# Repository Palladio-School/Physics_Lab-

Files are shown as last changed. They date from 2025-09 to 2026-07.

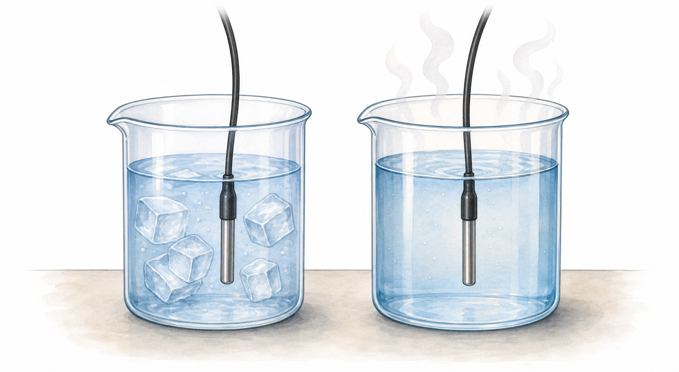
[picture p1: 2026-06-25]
docs/assets/heat-ds18b20-illustration.png

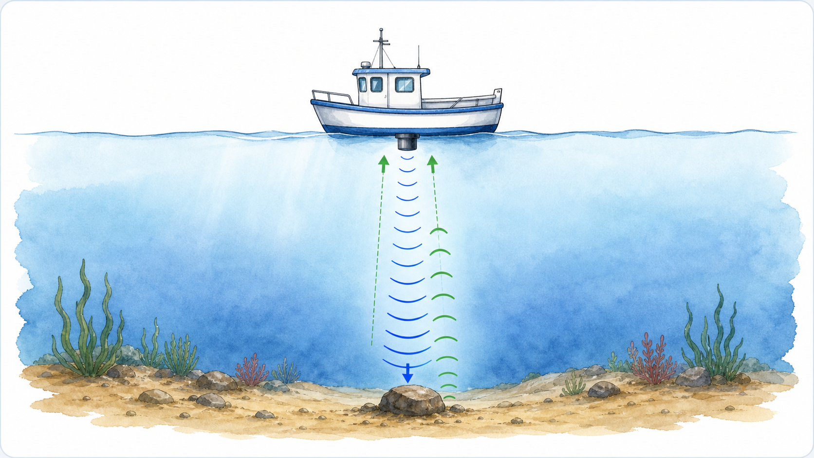
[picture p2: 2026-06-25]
docs/assets/sonar-distance-illustration.png

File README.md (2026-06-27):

# Palladio Physics Lab

Palladio Physics Lab is a classroom physics toolkit for live, low-cost experiments with an M5StickC Plus2 and common sensors. The current classroom path is browser-based: the M5Stick creates its own Wi-Fi access point, exposes a small HTTP API, and serves a dashboard that students or teachers open from a laptop, tablet, or phone.

The repository also keeps the earlier Python desktop application for reference and compatibility, but new classroom work should start from the M5 firmware and web dashboard.

## What It Supports

- Live acceleration and gyroscope measurements from the M5StickC Plus2.
- Load-cell force measurements through an HX711 module.
- Ultrasonic distance, velocity, and acceleration measurements through a DFRobot URM10 ultrasonic sensor.
- Temperature / thermal-equilibrium measurements through DS18B20 sensors.
- A browser dashboard with experiment selection, live graphs, CSV export, worksheet/report flows, calibration controls, and sampling-rate controls.
- A legacy Python desktop app that can still listen to UDP broadcasts from the M5.

## Repository Map

| Path | Purpose |
| --- | --- |
| `Physics_Lab/Physics_Lab.ino` | Main Arduino firmware for the M5StickC Plus2. It creates the Wi-Fi AP, reads sensors, serves API endpoints, and emits UDP packets for the legacy desktop app. |
| `Physics_Lab/web_dashboard.h` | Lightweight firmware-served API status page embedded into the sketch. |
| `Physics_Lab/logo_asset.h` | Generated C header containing the Palladio logo bytes for firmware use. |
| `Physics_Lab/assets/` | Firmware-side project assets, currently the Palladio logo. |
| `Physics_Lab/scripts/arduino.sh` | Helper for compiling, cleaning, checking Arduino CLI version, and uploading firmware. |
| `Physics_Lab/PROJECT_HISTORY.md` | Development notes and operational history for the current M5/web-dashboard direction. |
| `docs/index.html` | Full GitHub Pages / browser dashboard. This is the current large UI surface and should be changed carefully. |
| `docs/assets/` | Dashboard images and experiment illustrations. |
| `physics_lab_with_angular_velocity.py` | Legacy CustomTkinter desktop app. |
| `requirements.txt` | Python dependencies for the legacy desktop app. |
| `case2.stl`, `cover.stl` | 3D-printable case/cover assets. |
| `PROJECT_STRUCTURE.md` | More detailed technical structure and known hot spots. |
| `HARDWARE_API.md` | Hardware wiring notes, firmware API reference, UDP compatibility, and verification checklist. |
| `UI_FLOW.md` | Student and teacher dashboard flow, classroom checklist, and current UI state model. |

## Run The Web Dashboard

The full dashboard lives in `docs/index.html`. To inspect it locally:

```bash
python3 -m http.server 8000 -d docs
```

Then open:

```text
http://localhost:8000
```

If GitHub Pages is enabled for the repository, it should serve the same `docs/` dashboard.

## Dashboard Safety Checks

The dashboard has lightweight regression checks for extracted helper files and the browser-only GitHub Pages surface:

```bash
npm install
npm test
```

If Playwright has not downloaded Chromium on the machine yet:

```bash
npx playwright install chromium
```

The browser smoke test serves `docs/` locally with mocked M5-shaped API responses, verifies the `docs/js/*.js` load order, checks for console/page errors, and switches through Hooke, Sonar, Pendulum, and Collision views.

For hardware-backed measurements, upload the firmware to the M5StickC Plus2 and use the device access point:

1. Upload `Physics_Lab/Physics_Lab.ino` to the M5StickC Plus2.
2. Power on or reset the M5StickC Plus2.
3. Connect the laptop, tablet, or phone to this Wi-Fi network:

```text
PhysicsLab-M5
```

4. Open this address in a browser:

```text
http://192.168.4.1
```

The M5 serves the live API from `192.168.4.1`. The full dashboard can use that API when the browser is connected to the M5 network.

## Upload Firmware

The helper script expects Arduino CLI either in `PATH`, in the standard macOS Arduino IDE bundle location, or through `ARDUINO_CLI`.

```bash
cd Physics_Lab
./scripts/arduino.sh compile
./scripts/arduino.sh upload /dev/cu.usbserial-0001
```

If the upload port changes, list boards with:

```bash
'/Applications/Arduino IDE.app/Contents/Resources/app/lib/backend/resources/arduino-cli' board list
```

The default board identifier is:

```text
m5stack:esp32:m5stack_stickc_plus2
```

Override it only when testing a different compatible board:

```bash
ARDUINO_FQBN=<fqbn> ./scripts/arduino.sh compile
```

## API Surface

The firmware exposes these browser-facing endpoints:

- `/` - lightweight device/API status page from the firmware.
- `/logo.png` - embedded Palladio logo.
- `/data` - latest device state and current readings.
- `/samples?since=<sampleId>` - batched sample retrieval without duplicating already-recorded samples.
- `/set-mode?mode=<n>` - switch active sensor/experiment mode.
- `/settings?rate=<hz>` - set supported sampling rate.
- `/calibrate?target=<name>` - run sensor zero/tare calibration for the active target.

The firmware also keeps UDP output for the legacy desktop app:

- `4210` acceleration / force from accelerometer
- `4211` angular velocity
- `4213` load-cell force
- `4215` ultrasonic motion
- `4216` temperature

## Hardware

Core hardware:

- M5StickC Plus2
- USB-C cable
- Laptop, tablet, or phone with Wi-Fi

Optional experiment hardware:

- HX711 module and load cell for force / Hooke-law style experiments
- DFRobot URM10 ultrasonic sensor for distance and motion
- DS18B20 temperature sensors for thermal-equilibrium experiments
- Breadboard and jumper wires

Current firmware pin notes:

- DFRobot URM10: `TRIG_PIN = 26`, `ECHO_PIN = 25`
- HX711: `DT = 36`, `DT_ALT = 25`, `SCK = 26`
- DS18B20: `TEMP1_PIN = 25`, `TEMP2_PIN = 26`

On startup the firmware attempts to detect the connected external sensor family and selects the matching mode automatically: DS18B20 heat first, then URM10 ultrasonic, then HX711 force. Manual mode selection from the dashboard or M5 buttons remains available.

Some pins are shared across experiment modes. Treat this as a documented hardware constraint until the wiring plan is finalized per lab setup.
With the current wiring, the DFRobot URM10 and the two DS18B20 sensors both use `G25/G26`, so do not keep them connected at the same time.

## Run The Legacy Desktop App

The Python app is still useful for reference, older demos, and UDP compatibility checks.

```bash
python3 -m venv .venv
source .venv/bin/activate
pip install -r requirements.txt
python physics_lab_with_angular_velocity.py
```

## Known Hot Spots

- `docs/index.html` is currently a large single-file dashboard. Prefer documentation and small isolated changes before deep UI refactoring.
- The dashboard polls the M5 API frequently. Firmware sample IDs reduce duplicate samples, but performance should still be watched on lower-power devices.
- Sensor wiring and shared pins need a stable classroom-facing hardware guide before broad use.
- Arduino compile/upload validation depends on a local Arduino CLI + M5Stack board setup.
- The legacy Python app and current browser dashboard now describe different generations of the project; keep future changes explicit about which path they affect.

See `PROJECT_STRUCTURE.md` for the fuller technical map.
See `HARDWARE_API.md` for the hardware and API reference.
See `UI_FLOW.md` for the student and teacher classroom flow.

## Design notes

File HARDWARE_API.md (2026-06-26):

# Hardware And API Reference

This document describes the current M5StickC Plus2 hardware contract and firmware API used by the Palladio Physics Lab dashboard. It is documentation-only: it records the current implementation so future hardware, UI, and performance work can be reviewed against a shared map.

## Current Hardware Role

The M5StickC Plus2 is the measurement device and local API server.

- It creates the Wi-Fi network `PhysicsLab-M5`.
- It serves HTTP on `http://192.168.4.1`.
- It samples the active sensor mode at the configured rate.
- It exposes the latest reading and a rolling sample buffer through HTTP.
- It still broadcasts UDP packets for the legacy Python desktop app.

The full classroom dashboard in `docs/index.html` defaults to `http://192.168.4.1`, but can be pointed to another device URL with:

```text
?device=http://192.168.4.1
```

The selected device URL is stored in browser `localStorage` under `palladio-device-url`.

## Sensor Modes

| Mode | Firmware name | Dashboard use | Hardware |
| --- | --- | --- | --- |
| `0` | `Acceleration` | Acceleration, force-from-acceleration activities | Built-in M5StickC Plus2 IMU |
| `1` | `Gyroscope` | Rotation / angular velocity | Built-in M5StickC Plus2 IMU |
| `2` | `Load Cell` | Force, Hooke's law, buoyancy force readings | HX711 + load cell |
| `3` | `WiFi Info` | Device network status on the M5 display | M5StickC Plus2 only |
| `4` | `Ultrasonic` | Distance, speed, acceleration, sonar-style activities | DFRobot URM10 ultrasonic sensor |
| `5` | `Temperature` | Heat / thermal-equilibrium activities | Two DS18B20 temperature sensors |

The M5 buttons also cycle modes:

- Button A: next mode
- Button B: previous mode

Changing mode clears the sample buffer and resets mode-specific state.

## Pin Map

Current firmware definitions:

```cpp
#define TRIG_PIN 26
#define ECHO_PIN 25
#define DT 36
#define DT_ALT 25
#define SCK 26
#define TEMP1_PIN 25
#define TEMP2_PIN 26
```

| Sensor | Signal | M5 pin | Notes |
| --- | --- | --- | --- |
| DFRobot URM10 | Trigger | `G26` | Shared with HX711 SCK and DS18B20 T2 in the current firmware. |
| DFRobot URM10 | Echo | `G25` | Input. Powered from 3V in the current classroom wiring. Shared with HX711 alternate DOUT and DS18B20 T1. |
| HX711 | DOUT primary | `G36` | Firmware starts here. |
| HX711 | DOUT alternate | `G25` | Firmware can switch here if the primary path looks unavailable. |
| HX711 | SCK | `G26` | Shared with ultrasonic trigger and DS18B20 T2. |
| DS18B20 T1 | Data | `G25` | Shared with HX711 alternate DOUT. |
| DS18B20 T2 | Data | `G26` | Shared with HX711 SCK and ultrasonic trigger. |

Because some pins are shared, treat the current setup as one active external sensor family at a time unless a final wiring harness proves otherwise.
In particular, the DFRobot URM10 and the two DS18B20 temperature sensors both occupy `G25/G26`; disconnect one sensor family before testing the other.

On startup the firmware runs a conservative sensor auto-detection pass. It checks for two DS18B20 sensors first, then URM10, then HX711. The URM10 check runs before the HX711 alternate `DT_ALT = G25` check so the shared echo/DOUT pin is not misclassified as a load-cell signal. If exactly one sensor family is found, the M5 selects that mode automatically. If nothing is found or the wiring is ambiguous, it falls back to manual mode selection.

## Hardware Notes By Experiment

### Built-In IMU

Modes:

- `0` acceleration
- `1` gyroscope

No external wiring is required. The firmware converts acceleration readings to m/s² by multiplying raw accelerometer values by `9.81`.

### HX711 Load Cell

Mode:

- `2` load cell / force

Current firmware behavior:

- Uses `SCALE_FACTOR = 48163.7`.
- Starts with `DT = 36`, `SCK = 26`.
- If the HX711 is not ready or keeps returning raw zero, the firmware can try `DT_ALT = 25`.
- `calibrate?target=force` runs `scale.tare(10)`.
- Force is reported in newtons as `force`.

Open verification items:

- Confirm the load-cell capacity and mechanical mounting.
- Confirm final DOUT pin for the classroom harness.
- Calibrate `SCALE_FACTOR` against known masses before treating force values as final.

### Ultrasonic Sensor

Mode:

- `4` ultrasonic

Current firmware behavior:

- Trigger pin: `G26`.
- Echo pin: `G25`.
- Sends a 10 microsecond trigger pulse.
- Uses `pulseIn(ECHO_PIN, HIGH, 30000)`.
- Converts duration to distance with speed of sound in air: `duration * 0.0343 / 2`.
- Rejects readings below 2 cm or above 200 cm.
- Applies smoothing: previous smoothed value `60%`, new reading `40%`.
- Computes distance in meters, velocity in m/s, and acceleration in m/s² from sample timing.
- `calibrate?target=distance` zeroes the current distance as an offset and resets velocity/acceleration state.

Open verification items:

- Confirm the URM10 is powered from the M5 `3V` pin so the echo signal stays 3.3 V logic compatible.
- Test known distances in the intended classroom range.
- Confirm that smoothing is appropriate for fast-motion experiments.

### DS18B20 Temperature Sensors

Mode:

- `5` temperature

Current firmware behavior:

- Sensor 1 data pin: `G25`.
- Sensor 2 data pin: `G26`.
- Uses two OneWire buses and DallasTemperature.
- Sets both sensors to 11-bit resolution.
- Reports `temp1`, `temp2`, and `tempDelta = temp1 - temp2`.
- Skips a sample if either sensor reports disconnected.

Open verification items:

- Confirm whether the final harness uses one shared OneWire bus or two separate buses.
- Confirm pull-up resistor placement.
- Test response time in the actual thermal-equilibrium setup.

## HTTP API

Base URL when connected to the M5 access point:

```text
http://192.168.4.1
```

The firmware includes CORS headers:

- `Access-Control-Allow-Origin: *`
- `Access-Control-Allow-Methods: GET, OPTIONS`
- `Access-Control-Allow-Headers: Content-Type`
- `Access-Control-Allow-Private-Network: true`

### `GET /`

Returns the lightweight firmware-served status page from `Physics_Lab/web_dashboard.h`.

This is not the full classroom dashboard in `docs/index.html`.

### `GET /logo.png`

Returns the embedded Palladio logo from `logo_asset.h`.

### `GET /data`

Returns the latest device state and latest sample values.

Example shape:

```json
{
  "mode": 0,
  "modeName": "Acceleration",
  "ap": "PhysicsLab-M5",
  "ip": "192.168.4.1",
  "battery": 4.05,
  "sampleId": 123,
  "sampleMs": 45678,
  "sampleRate": 10,
  "ax": 0.012,
  "ay": -0.034,
  "az": 9.801,
  "gx": 0.000,
  "gy": 0.000,
  "gz": 0.000,
  "force": 0.000,
  "distance": 0.000,
  "velocity": 0.000,
  "acceleration": 0.000,
  "temp1": 0.000,
  "temp2": 0.000,
  "tempDelta": 0.000
}
```

Notes:

- Values for inactive sensor families may remain from the last sampled value or default to zero.
- `sampleMs` is firmware time from `millis()`, not browser time.
- `sampleId` increases only when the active mode produces a valid sample.

### `GET /samples`

Returns the rolling sample buffer.

```text
GET /samples
GET /samples?since=<sampleId>
```

Response shape:

```json
{
  "mode": 4,
  "modeName": "Ultrasonic",
  "ap": "PhysicsLab-M5",
  "ip": "192.168.4.1",
  "battery": 4.02,
  "sampleRate": 10,
  "latestId": 123,
  "bufferCount": 120,
  "samples": [
    {
      "mode": 4,
      "sampleId": 122,
      "sampleMs": 45600,
      "sampleRate": 10,
      "battery": 4.02,
      "ax": 0.000,
      "ay": 0.000,
      "az": 0.000,
      "gx": 0.000,
      "gy": 0.000,
      "gz": 0.000,
      "force": 0.000,
      "distance": 0.340,
      "velocity": 0.120,
      "acceleration": -0.030,
      "temp1": 0.000,
      "temp2": 0.000,
      "tempDelta": 0.000
    }
  ]
}
```

Notes:

- The firmware stores up to 512 samples in a circular buffer.
- `since` filters samples with `sampleId > since`.
- If there are no newer samples, `samples` is an empty array.
- The dashboard polls this endpoint first and falls back to `/data`.

### `GET /set-mode?mode=<n>`

Switches active mode and returns the same shape as `/data`.

Valid modes:

- `0` acceleration
- `1` gyroscope
- `2` load cell
- `3` Wi-Fi info
- `4` ultrasonic
- `5` temperature

Changing mode:

- configures mode-specific hardware,
- clears the sample buffer,
- resets distance/velocity state,
- resets sampling schedule,
- updates the M5 display.

### `GET /settings?rate=<hz>`

Updates sample rate and returns the same shape as `/data`.

Accepted rates:

- `1`
- `2`
- `5`
- `10`
- `20`
- `50`
- `100`

Notes:

- The default rate is 10 Hz.
- Entering load-cell mode forces the rate back to 10 Hz.
- The dashboard exposes the same values in its sampling-rate dropdown.

### `GET /calibrate?target=<name>`

Runs calibration/zeroing for the requested target and returns the same shape as `/data`.

Valid targets:

| Target | Effect |
| --- | --- |
| `accel` | Stores current raw acceleration as offset and reports zeroed acceleration. |
| `gyro` | Stores current raw gyroscope values as offset and reports zeroed angular velocity. |
| `force` | Runs HX711 tare with 10 samples and resets force zero state. |
| `distance` | Adds current distance to the distance offset and resets velocity/acceleration state. |

The current dashboard maps calibration buttons by active mode:

- mode `0` -> `accel`
- mode `1` -> `gyro`
- mode `2` -> `force`
- mode `4` -> `distance`

## UDP Compatibility

The firmware continues to broadcast UDP packets to:

```text
192.168.4.255
```

Current ports:

| Port | Mode | Payload |
| --- | --- | --- |
| `4210` | acceleration | `ax,ay,az,battery` |
| `4211` | gyroscope | `gx,gy,gz,battery` |
| `4213` | load cell | `force,battery` |
| `4215` | ultrasonic | `distance,velocity,acceleration` |
| `4216` | temperature | `temp1,temp2,tempDelta,battery` |

The legacy desktop app depends on these broadcasts. New browser work should prefer HTTP `/samples` and `/data`.

## Dashboard API Behavior

The full dashboard:

- builds API URLs from `deviceBaseUrl`;
- defaults to `http://192.168.4.1`;
- polls `/samples?since=<lastSampleId>`;
- falls back to `/data` if `/samples` fails;
- schedules polling adaptively from the active sample rate instead of using a fixed 30 ms hardware loop;
- polls more slowly while measurement is idle and backs off when the M5 is offline;
- temporarily uses `/data` first when `/samples` is unavailable, then retries `/samples` periodically;
- uses firmware `sampleId` and `sampleMs` to avoid duplicate samples and browser-time drift;
- sends `/set-mode`, `/settings`, and `/calibrate` through simple GET requests.

The pendulum experiment is digital-only and does not require M5 hardware.

## Verification Checklist

Before broad classroom use, verify with the actual hardware kit:

- M5 boots and advertises `PhysicsLab-M5`.
- Browser can reach `http://192.168.4.1/data`.
- `/samples?since=0` returns sample objects in each hardware mode.
- Built-in acceleration reads near `9.81 m/s²` on the gravity axis before zeroing.
- Gyroscope reads near zero when stationary after calibration.
- HX711 tare works and known masses produce stable force readings.
- Ultrasonic readings match known distances in the expected range.
- DS18B20 sensors both report plausible temperatures and `tempDelta` behaves as expected.
- Dashboard mode switching matches firmware mode switching.
- UDP compatibility still works for the legacy Python app when needed.

## Known Hardware/API Risks

- Several external sensor definitions share pins (`G25`, `G26`). Do not assume simultaneous external sensor wiring until a final harness is tested.
- URM10 echo voltage must be checked against the M5 input tolerance if the wiring changes from the current 3V setup.
- Load-cell calibration factor is currently code-defined and should be validated against known masses.
- Adaptive polling is UI-side behavior; firmware sample IDs protect data quality, but performance should still be measured on classroom devices.
- `/data` returns one flat object for all sensor families, so consumers should read only the fields relevant to the active mode.
- API changes should preserve `sampleId`, `sampleMs`, and `/samples?since=` semantics because the dashboard depends on them.

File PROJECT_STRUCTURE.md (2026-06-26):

# Project Structure

This file maps the current repository before larger documentation, hardware, UI, or performance work. The goal is to make the first cleanup step readable without changing the dashboard implementation.

## Current Product Shape

Physics Lab has two generations in the same repository:

1. Current M5/web-dashboard flow
   - `Physics_Lab/Physics_Lab.ino` runs on the M5StickC Plus2.
   - The M5 creates the `PhysicsLab-M5` Wi-Fi network and exposes the hardware API at `http://192.168.4.1`.
   - `docs/index.html` is the full classroom dashboard, suitable for GitHub Pages or local browser use.

2. Legacy desktop flow
   - `physics_lab_with_angular_velocity.py` is a Python / CustomTkinter app.
   - The firmware still broadcasts UDP packets for compatibility with this app.

New work should state which flow it changes.

## Directory And File Responsibilities

### Root

- `README.md` - main project entry point for teachers, developers, and maintainers.
- `PROJECT_STRUCTURE.md` - this technical map.
- `HARDWARE_API.md` - hardware wiring notes, firmware API reference, UDP compatibility, and verification checklist.
- `UI_FLOW.md` - student and teacher dashboard flow, classroom checklist, and current UI state model.
- `requirements.txt` - Python dependencies for the legacy desktop app only.
- `physics_lab_with_angular_velocity.py` - legacy desktop application.
- `case2.stl`, `cover.stl` - 3D-printing assets for the device/case.

### `Physics_Lab/`

- `Physics_Lab.ino` - main firmware sketch.
- `web_dashboard.h` - embedded lightweight device status page.
- `logo_asset.h` - generated byte-array logo asset.
- `assets/palladio-logo.png` - source logo asset used for firmware embedding.
- `PROJECT_HISTORY.md` - project-local history and operational notes.
- `scripts/arduino.sh` - Arduino CLI helper.

### `docs/`

- `index.html` - full browser dashboard UI.
- `.nojekyll` - keeps GitHub Pages from applying Jekyll processing.
- `assets/` - dashboard illustrations and experiment images.

## Firmware Responsibilities

The firmware:

- Creates the M5 Wi-Fi access point.
- Reads the active sensor mode.
- Maintains `sampleId`, `sampleMs`, and `sampleRate` so browser polling does not duplicate samples.
- Serves the latest reading and sample batches through HTTP.
- Handles mode changes, sampling-rate changes, and calibration requests.
- Keeps UDP compatibility with the older Python app.

Important endpoints:

- `/`
- `/logo.png`
- `/data`
- `/samples`
- `/set-mode`
- `/settings`
- `/calibrate`

## Dashboard Responsibilities

The full dashboard in `docs/index.html` handles:

- Experiment selection.
- Live graphing and readouts.
- Student-facing worksheet/report interactions.
- CSV export.
- Sampling-rate and calibration controls.
- Digital-only experiments such as the pendulum simulation.
- M5 API polling through the `192.168.4.1` device endpoint when hardware is connected.

Because it is currently a large single HTML file, changes should be narrow and easy to review.

## Hardware Matrix

| Experiment / Mode | Hardware | Firmware Notes |
| --- | --- | --- |
| Acceleration | M5StickC Plus2 IMU | Built-in sensor. |
| Gyroscope | M5StickC Plus2 IMU | Built-in sensor. |
| Force / load cell | HX711 + load cell | Uses `DT`, `DT_ALT`, and `SCK` candidates. |
| Ultrasonic motion | DFRobot URM10 ultrasonic sensor | Uses trigger/echo pins and firmware-side timing. |
| Heat / thermal equilibrium | DS18B20 sensors | Uses two OneWire data pins. |
| Pendulum simulation | No M5 required | Digital dashboard experiment. |

Current pin definitions in `Physics_Lab.ino`:

```cpp
#define TRIG_PIN 26
#define ECHO_PIN 25
#define DT 36
#define DT_ALT 25
#define SCK 26
#define TEMP1_PIN 25
#define TEMP2_PIN 26
```

Firmware startup performs conservative sensor auto-detection. It selects Heat when both DS18B20 sensors are found, Ultrasonic when the URM10 responds to trigger/echo timing, and Force when HX711 is found. Manual selection remains available from the dashboard and M5 buttons.

Pin sharing is intentional in the current firmware mode layout, but it should be documented in a classroom wiring guide before hardware kits are handed out broadly.

## Developer Workflow

Compile firmware:

```bash
cd Physics_Lab
./scripts/arduino.sh compile
```

Upload firmware:

```bash
cd Physics_Lab
./scripts/arduino.sh upload /dev/cu.usbserial-0001
```

Run the legacy app:

```bash
python3 -m venv .venv
source .venv/bin/activate
pip install -r requirements.txt
python physics_lab_with_angular_velocity.py
```

Inspect the full dashboard locally:

```bash
python3 -m http.server 8000 -d docs
```

Then open:

```text
http://localhost:8000
```

## Known Review Points

- `docs/index.html` should eventually be split into smaller assets/modules, but that should be a separate PR.
- The README and project history should stay aligned so users know whether instructions refer to the current M5/browser flow or the legacy Python flow.
- A hardware/API guide should be the next documentation layer: wiring diagrams, pin choices, calibration steps, expected sensor ranges, and safety notes.
- Polling/performance work should be measured against actual M5 hardware and classroom browser devices.
- GitHub Pages and M5-served firmware pages are different surfaces; future docs should keep that deployment model clear.

## Suggested Next PRs

1. Polling and performance cleanup.
2. Controlled `docs/index.html` modularization.

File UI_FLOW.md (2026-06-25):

# Student And Teacher UI Flow

This document maps the current browser dashboard flow in `docs/index.html` for classroom use. It is documentation-only: it records how the dashboard is intended to be used before any UI refactor or product redesign.

## Audience And Surfaces

The dashboard serves two classroom roles:

- Students use the experiment menu, live chart, student guide, worksheets, and CSV/export actions while collecting data.
- Teachers use the same dashboard plus the right-side experiment panels, calibration controls, sampling controls, trial tables, and export/review tools to prepare and guide the activity.

The dashboard can run from:

- GitHub Pages or a local `docs/` server while pointing at the M5 API.
- The M5 access point at `http://192.168.4.1` for hardware-backed measurements.
- A local browser-only mode for digital activities such as the pendulum simulation.

## Student Flow

### 1. Choose the activity

Students start from the left experiment menu. The current dashboard groups activities by school level:

| Group | Activities |
| --- | --- |
| A Gymnasium | Distance and time, SONAR, average speed, mass/weight and spring extension, heat, simple pendulum |
| B Gymnasium | Uniform motion, Hooke's law, buoyancy, rotation |
| Technical sensor modes | Acceleration, gyroscope, force, ultrasonic, heat |

Selecting an activity updates the title, description, graph setup, active sensor mode, and the student guide prompts. The selected activity is stored in browser `localStorage` as `palladio-active-experiment`.

### 2. Connect to the measurement source

For hardware-backed activities, the student device should be connected to the `PhysicsLab-M5` Wi-Fi network and use the M5 API at:

```text
http://192.168.4.1
```

The dashboard stores the chosen device URL in `localStorage` as `palladio-device-url`. When the dashboard is opened with a query parameter such as:

```text
?device=http://192.168.4.1
```

that value becomes the active measurement source.

The simple pendulum activity is digital-only and does not require the M5.

### 3. Measure

The primary student controls are in the instrument bar:

- `Έναρξη` starts or pauses live collection.
- `Νέα μέτρηση` clears the visible run and starts a fresh trial.
- `Αποθήκευση CSV` exports the current data.
- The calibration button runs the relevant zero/tare action when the active sensor supports it.

During live collection, the student guide treats the first state as measurement. The chart updates from `/samples?since=<sampleId>` when available, with `/data` as a fallback.

### 4. Observe

After samples exist, students inspect the graph:

- Toggle plotted series from the legend.
- Use value inspection to read a point.
- Use selection mode to mark an A-B region.
- Use pan/zoom and the `Live` control to move between a fixed view and real-time tracking.
- Use split view or experiment-specific chart modes where available.

For ultrasonic activities, the dashboard keeps one main series active at a time so distance, velocity, and acceleration are easier to compare without clutter.

### 5. Conclude

When students select an A-B region, the guide moves toward conclusion. The current dashboard supports this through:

- A-B selection statistics and graph annotations.
- Experiment-specific panels and tables for trials.
- Worksheet text areas for observations and conclusions.
- CSV export for follow-up analysis.

The main student loop is:

```text
Choose activity -> Start measurement -> Observe chart -> Select evidence -> Write conclusion -> Export or reset
```

## Teacher Flow

### 1. Prepare the setup

Before students start, the teacher should choose the activity and confirm that the dashboard selected the expected hardware mode:

| Activity type | Expected source |
| --- | --- |
| Acceleration / motion with IMU | Mode `0`, built-in M5 IMU |
| Rotation | Mode `1`, built-in M5 gyroscope |
| Force / Hooke / buoyancy | Mode `2`, HX711 + load cell |
| Distance / SONAR / speed | Mode `4`, ultrasonic sensor |
| Heat | Mode `5`, DS18B20 sensors |
| Pendulum | Browser simulation, no M5 polling |

Some activities apply defaults automatically. For example, force activities prefer a 10 Hz sampling rate, heat uses a longer time window, and pendulum stops hardware polling because it is simulated in-browser.

### 2. Calibrate and check readings

Teacher-facing calibration depends on the selected mode:

- Force / load cell: tare the load cell before hanging masses or collecting buoyancy data.
- Ultrasonic: zero the distance offset if the setup needs a reference position.
- Acceleration: use the built-in IMU readings as the baseline for acceleration activities.

Before distributing the activity, confirm:

- The live readout changes when the sensor changes.
- The graph updates at the intended rate.
- Units match the activity.
- The first few samples look plausible for the physical setup.

### 3. Guide the live activity

The right-side rail is the teacher's main review and facilitation area. It contains experiment-specific panels for:

- Hooke's law and force-extension work.
- Mass/weight and spring extension.
- Buoyancy force trials.
- Motion, collision, and ultrasonic analysis.
- Heat / thermal equilibrium.
- Pendulum timing and analysis.

The rail can be collapsed or resized so a projector view can emphasize either the graph or the teacher panels.

### 4. Review student evidence

During or after collection, the teacher can ask students to compare:

- Raw graph shape.
- A-B selection statistics.
- Repeated trials in the experiment tables.
- Worksheet observations and conclusion text.
- Exported CSV data when a deeper analysis is needed.

The dashboard stores several trial sets in browser `localStorage`, including collision, Hooke, weight, pendulum, and buoyancy trial data. This makes quick classroom iteration possible, but it is not a long-term student record system.

### 5. Export or reset

The teacher can use the generic CSV export or experiment-specific exports where present:

- Hooke trial export.
- Mass/weight extension export.
- Buoyancy export.
- Collision export.
- Pendulum export.

Use `Νέα μέτρηση` when the next group needs a clean run. For a completely clean classroom device, clear browser storage or use a fresh browser profile.

## Current UI State Model

The dashboard uses a simple student-guide state:

| State | Trigger | Student meaning |
| --- | --- | --- |
| Measure | Running or no sample data yet | Collect data from the device or simulation. |
| Observe | Samples exist, no A-B selection | Read the graph and compare visible series. |
| Conclude | A-B selection exists | Use selected evidence to write or discuss the conclusion. |

This state model should remain visible in future UI work because it matches the classroom rhythm of measurement, observation, and conclusion.

## Classroom Checklist

Before class:

- Upload current firmware to the M5StickC Plus2.
- Confirm the M5 starts the `PhysicsLab-M5` Wi-Fi network.
- Connect one browser device and open the dashboard.
- Select the intended experiment.
- Confirm sensor mode, sample rate, and units.
- Run calibration when the activity needs it.
- Collect a short test run and export CSV once.

During class:

- Keep one projected dashboard as the reference view.
- Use the student guide to keep the flow on measure, observe, conclude.
- Use A-B selection when asking for evidence.
- Reset between groups or trials.

After class:

- Export useful CSV or trial tables.
- Note any sensor noise, connection drop, calibration drift, or confusing UI step.

## Known UI Flow Risks

- `docs/index.html` is a large single file, so even small UI behavior changes need careful review.
- Several teacher and student controls share the same screen; future design work should clarify role-specific views without hiding advanced controls from teachers.
- Browser `localStorage` is useful for classroom continuity but can surprise users if an old activity or trial set reappears.
- Hardware-backed activities depend on the browser reaching the M5 API; the UI should eventually make connection state and recovery clearer.
- The pendulum flow is digital-only while most other activities are hardware-backed, so documentation and UI labels should keep that difference explicit.

## Suggested Follow-Up PRs

1. Add screenshots or short classroom walkthrough images after the visual flow is accepted.
2. Review dashboard copy for student-facing Greek consistency.
3. Measure polling and rendering performance on actual classroom tablets/laptops.
4. Split `docs/index.html` into smaller modules only after the documented flow is stable.

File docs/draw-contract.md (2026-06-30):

# Draw Contract

Date: 2026-06-30

This note documents the current responsibilities of `draw()` in `docs/index.html`.
It is a safety contract for future refactors. It does not change runtime behavior.

## Scope

`draw()` is the central renderer for the main chart canvas. It currently handles:

- clearing and repainting the main canvas,
- choosing special chart paths before the standard renderer,
- computing chart geometry,
- drawing axes, gridlines, labels, and plot frame,
- drawing selected data series,
- highlighting the active A-B selection,
- drawing area-under-curve shading for the active analysis series,
- drawing trend/fit lines,
- drawing A/B markers,
- drawing hover markers and tooltip anchors,
- delegating pendulum scrub/highlight overlays.

## Special Render Paths

`draw()` exits early for these cases:

1. Hooke split chart: `isHookeExperimentMode() && splitChartActive()`
2. Hooke force-extension chart: `isHookeExperimentMode() && hookeChartView === 'extension'`
3. Generic split chart: `splitChartActive()`

Any future extraction must preserve this order. The Hooke-specific split and
extension paths take precedence over the generic split chart.

## Inputs Read By `draw()`

The function reads global dashboard state, including:

- `canvas`, `ctx`
- active mode/experiment predicates
- `hookeChartView`
- `selection`
- `analysisCache`
- `hoverPoint`
- `timeScaleMode`
- `valueScaleMode`
- current rows through `visibleRows()`
- enabled series through `enabledSeries()`
- view bounds through `getViewBounds()`
- scaling through `yScale()`, `selectedTimeScale()`, and `selectedValueScale()`

Because these are shared globals, extracting `draw()` directly would be risky
unless the state is passed through an explicit render-state object.

## Outputs And Side Effects

`draw()` mutates:

- the canvas pixels,
- `chartGeometry`, used later by pointer, hover, pan, zoom, selection, and
  tooltip code.

It also calls:

- `drawHookeSplitChart()`
- `drawHookeDxChart()`
- `drawSplitChart()`
- `drawPendulumTimeGuides()`
- `drawDataPath()`
- `drawPendulumScrubHighlight()`
- `showTooltip()`

Future changes must treat `chartGeometry` as part of the public internal
contract of the chart interaction loop.

## Behavior To Preserve

- Empty datasets show `Αναμονή για μετρήσεις...`.
- Y-axis padding switches at narrow canvas width: left pad `64` under `520px`,
  otherwise `82`.
- Selection shading is clipped to the visible x-range.
- Area shading is drawn only for the selected analysis series when it is visible.
- Fit lines are dashed and clipped to the selected analysis interval.
- A/B markers are shown only when the active analysis series is visible.
- Hover tooltip follows the nearest visible row by time.
- Pendulum time guides and scrub highlight remain part of the main chart path.

## Safe Next Steps

Good first extractions:

1. A pure `buildChartRenderState()` helper that returns geometry, scales, rows,
   and selected series without drawing.
2. A pure `chartPointForRow()` helper that converts row values to canvas points.
3. Small draw helpers for axes/grid and selection shading after screenshot or
   pixel-level characterization exists.

Avoid first:

- extracting pointer/pinch/wheel behavior together with drawing,
- changing `chartGeometry` shape,
- changing the special-path order,
- changing scale defaults or padding while refactoring.

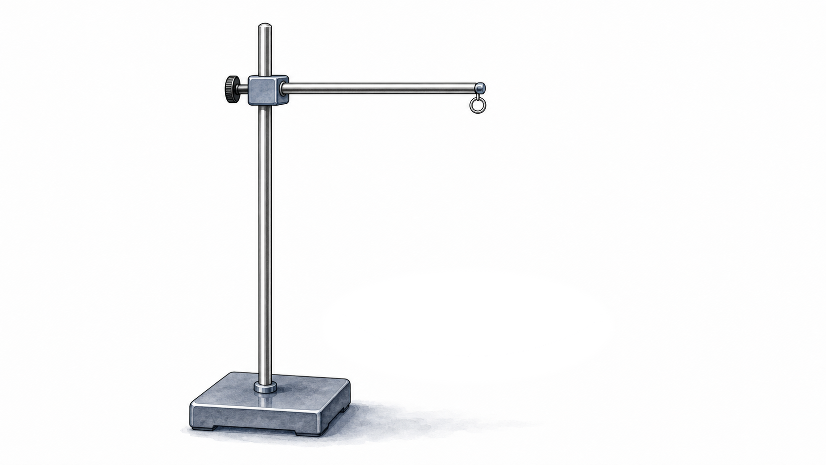
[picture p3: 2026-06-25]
docs/assets/pendulum-background-clean.png

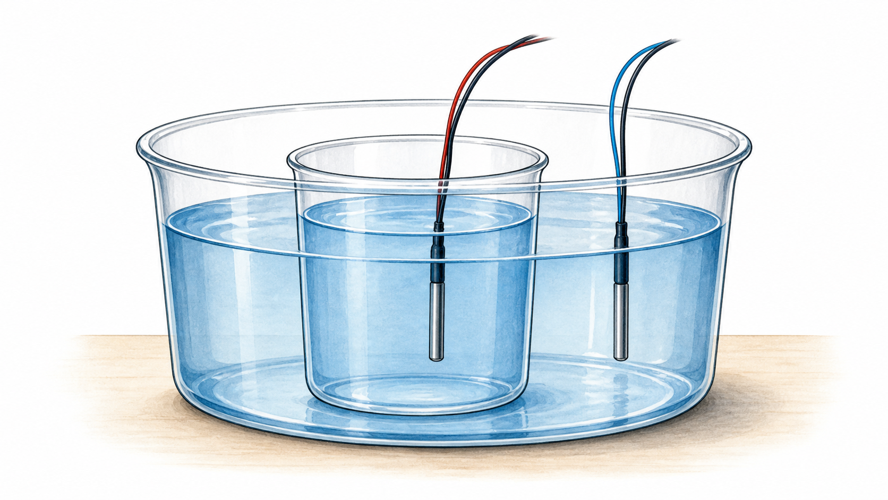
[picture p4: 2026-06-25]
docs/assets/heat-water-bath-illustration.png

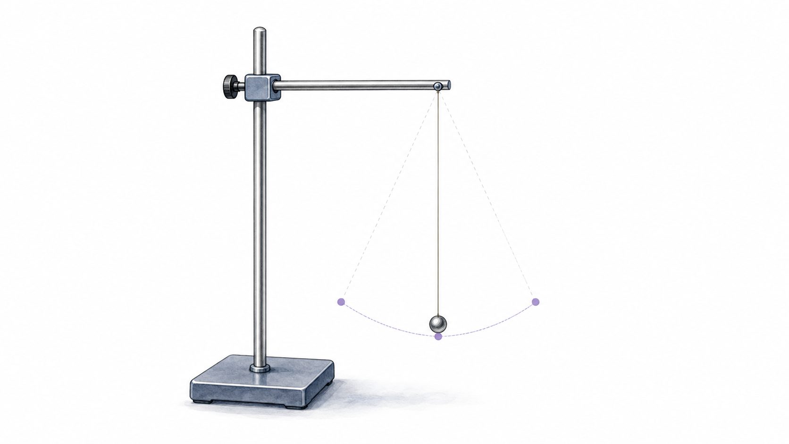
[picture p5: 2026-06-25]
docs/assets/pendulum-illustration.png

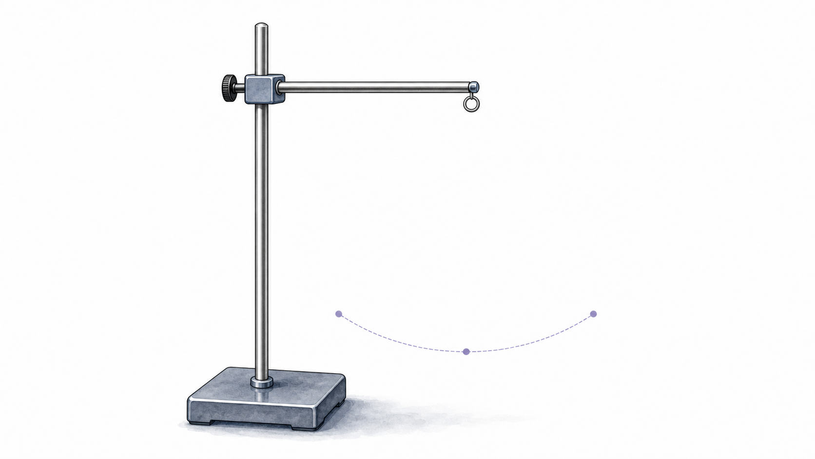
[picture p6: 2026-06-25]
docs/assets/pendulum-background-illustration.png

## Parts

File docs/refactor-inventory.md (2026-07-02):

# Refactor Inventory And Safety Net

Date: 2026-06-27

This is a documentation and test inventory only. It does not change dashboard runtime behavior, UI, firmware API, polling, or chart rendering.

## Current Size

- `docs/index.html`: 6,858 lines, 338,216 bytes.
- Extracted dashboard helpers in `docs/js/*.js`: 1,070 lines, 45,529 bytes.
- Largest remaining file by far: `docs/index.html`.

## Script Load Order

Current order in `docs/index.html`:

1. `js/experiment-catalog.js`
2. `js/app-config.js`
3. `js/device-client.js`
4. `js/storage-export.js`
5. `js/csv-row-utils.js`
6. `js/readout-utils.js`
7. `js/worksheet-utils.js`
8. `js/experiment-view-utils.js`
9. `js/sonar-utils.js`
10. `js/chart-utils.js`
11. `js/physics-calculations.js`
12. `js/fit-utils.js`
13. `js/pendulum-utils.js`
14. Inline dashboard app script

The order matters because `app-config.js` reads `window.PalladioExperimentCatalog`, `device-client.js` reads `window.PalladioConfig`, and the inline app reads all exported globals.

## Largest Remaining Blocks

Approximate ranges in `docs/index.html` after PR #15:

| Range | Lines | Area | Notes |
| --- | ---: | --- | --- |
| 927-6457 | 5,531 | Inline dashboard app | Main app state, renderers, chart drawing, events, startup. |
| 3483-5693 | 2,211 | Chart, analysis, selection, zoom | Highest-risk area. Includes `draw()` and pointer/wheel interactions. |
| 1519-3481 | 1,963 | Experiment renderers | Hooke, Sonar, Collision, Pendulum, Heat, and helper drawing code. |
| 5694-6438 | 745 | Event listeners and startup | Tightly coupled to DOM IDs and app state. |
| 977-1291 | 315 | State, element refs, row transforms | Mixed pure and UI-bound state. |
| 1-919 | 919 | HTML shell and experiment panels | Large but mostly declarative markup. |

The `draw()` function remains in place and should stay out of the next small extraction unless a stronger characterization suite is added first.
See [`draw-contract.md`](draw-contract.md) for the current chart rendering contract and safe extraction boundaries.

## Added Safety Net

- `tests/pure-helpers.test.js` loads the extracted global helper files in dependency order and checks:
  - catalog/config helpers,
  - experiment mode predicates and rail titles,
  - chart unit/format helpers,
  - weight and buoyancy calculations,
  - sonar echo-time normalization helpers,
  - pendulum period, sample, and interval helpers,
  - storage/export escaping and report generation,
  - CSV row builders for live series and saved experiment exports,
  - readout summary cards and empty table/message formatting,
  - worksheet list, Sonar worksheet row/data, and printable report helpers,
  - linear, Hooke, collision, linear-system, polynomial, and auto fit helpers.
- `tests/browser-smoke.spec.js` serves `docs/` locally with mocked M5-shaped API responses and checks:
  - script load order,
  - exported globals,
  - no `console.error` or uncaught page errors,
  - basic experiment switching for Hooke, Sonar, Pendulum, and Collision.

Run locally:

```bash
npm install
npm test
```

If Chromium is not installed for Playwright yet:

```bash
npx playwright install chromium
```

## Recommended Next Extraction Candidates

Good small PR candidates:

- More pendulum pure helpers if they stay DOM-free. The period/sample/interval helpers now live in `js/pendulum-utils.js`; keep canvas geometry and drawing in `index.html` unless separately characterized.
- More sonar helpers if they stay DOM-free. `sonarRoundTripTimeMs`, `firstFiniteNumber`, and echo-time conversion rules now live in `js/sonar-utils.js`; keep canvas drawing and drag handlers in `index.html`.
- More experiment view helpers if they stay DOM-free. Mode predicates and right-rail titles now live in `js/experiment-view-utils.js` and take an explicit state object.
- More CSV/export helpers if they stay DOM-free. Live series and saved experiment CSV rows now live in `js/csv-row-utils.js`; keep click handlers and `storageExport.downloadCsv` in `index.html`.
- More readout formatting helpers if they stay DOM-free. Summary cards and empty readouts now live in `js/readout-utils.js`; keep render decisions and DOM assignment in `index.html`.
- More worksheet/report helpers if they stay DOM-free. Motion worksheet lists and Sonar worksheet/report builders now live in `js/worksheet-utils.js`; keep user input collection and print-window opening in `index.html`.

Avoid for now:

- `draw()` and the chart interaction loop.
- `chartGeometry`, tooltip, selection, pan, zoom, and wheel/pinch handlers.
- Render functions that write directly to the DOM.
- Device polling, firmware API shape, and M5 request timing.

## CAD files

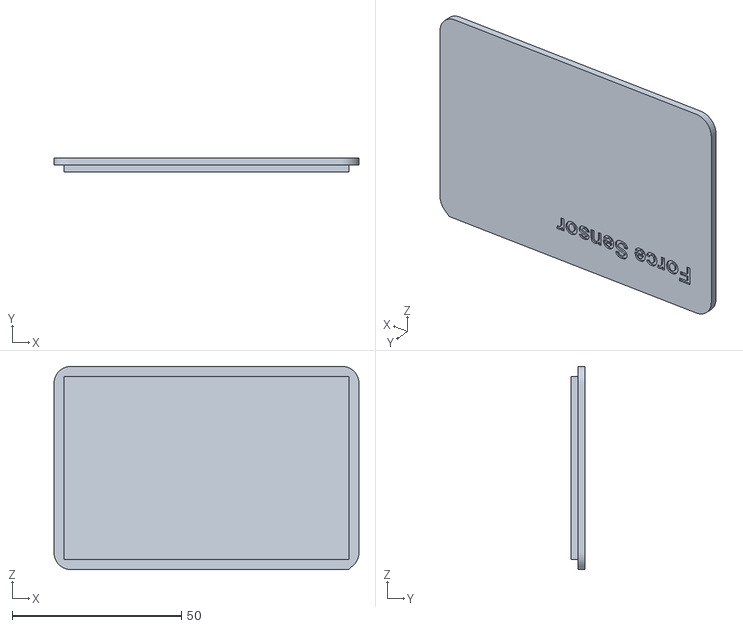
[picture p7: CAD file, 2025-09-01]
cover.stl
90.0 x 4.00 x 60.0

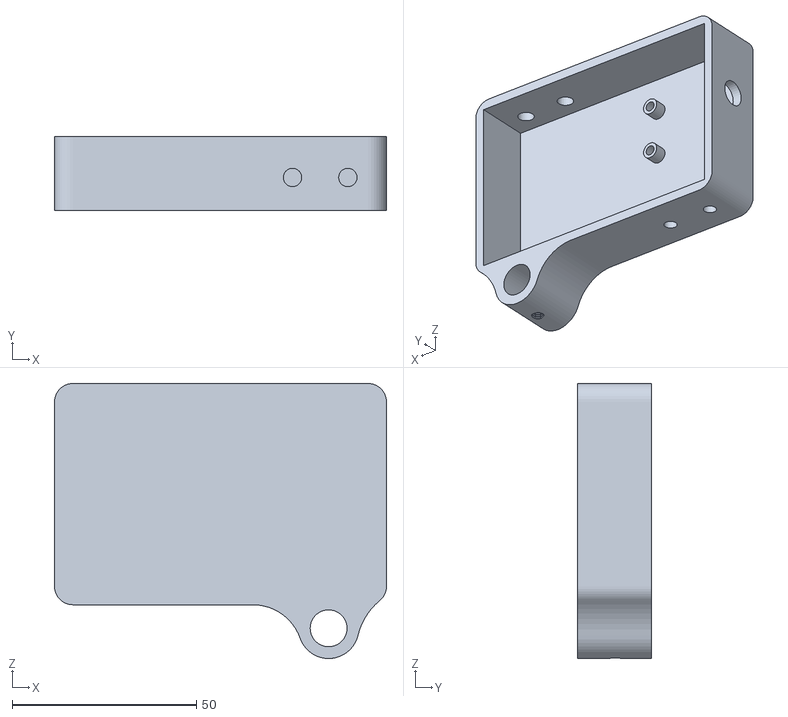
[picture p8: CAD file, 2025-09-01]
case2.stl
90.0 x 20.0 x 74.6

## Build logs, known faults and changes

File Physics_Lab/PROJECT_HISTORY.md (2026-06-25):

# Physics Lab Project History

Last updated: 2026-06-16

## Goal

Build a browser-based physics laboratory dashboard for the M5StickC Plus2. The M5Stick creates its own Wi-Fi network and serves the web app directly, so students connect to `PhysicsLab-M5` and open:

```text
http://192.168.4.1
```

## Current Status

The web app is embedded in the Arduino sketch and has been uploaded successfully to the M5StickC Plus2 several times during development.

Current main capabilities:

- Live web dashboard served from the M5StickC Plus2
- Modern sidebar UI with the Palladio logo
- Sensor modes: acceleration, gyroscope, load cell, ultrasonic motion
- Live chart with zoom, pan, series selection, and CSV export
- Analysis tools: A-B cursors, dt, dy, slope, mean, standard deviation, min/max, area, absolute area, fit equation, R2, RMSE
- Short educational examples next to each analysis/statistics tool
- Sampling-rate control: 5 Hz, 10 Hz, 20 Hz
- Firmware-side timestamps and sample IDs, so the browser does not create duplicate samples
- Calibration controls from the web UI:
  - accelerometer zero
  - gyroscope zero
  - load-cell tare
  - ultrasonic distance zero

## Files Changed Or Added

### `Physics_Lab.ino`

Main firmware sketch.

Important additions:

- Web endpoints:
  - `/`
  - `/logo.png`
  - `/data`
  - `/set-mode`
  - `/settings`
  - `/calibrate`
- Firmware-owned sampling:
  - `sampleId`
  - `sampleMs`
  - `sampleRate`
- Sampling interval control for 5/10/20 Hz
- Sensor zero/tare calibration handlers
- Serves the embedded Palladio logo as PNG

### `web_dashboard.h`

Embedded HTML/CSS/JavaScript for the web app.

Important additions:

- Full web app redesign
- Sidebar navigation and live readouts
- Palladio logo in the top-left sidebar
- Large central chart
- Chart tools:
  - inspect
  - select interval
  - pan
  - zoom in/out/live reset
- Analysis panel with statistics and physics examples
- CSV export
- Sampling-rate selector
- Calibration button that changes by sensor mode

### `logo_asset.h`

Generated C header containing the PNG logo bytes stored in flash memory.

### `assets/palladio-logo.png`

Optimized project copy of the Palladio logo used by the web app.

### `scripts/arduino.sh`

Helper script for compiling and uploading without opening Arduino IDE.

Common commands:

```bash
./scripts/arduino.sh compile
./scripts/arduino.sh upload /dev/cu.usbserial-5A490733351
```

### `.gitignore`

Ignores `.arduino/` build artifacts.

## Hardware / Board Setup

Detected board/core:

```text
M5StickCPlus2
FQBN: m5stack:esp32:m5stack_stickc_plus2
```

Arduino CLI is bundled inside Arduino IDE at:

```text
/Applications/Arduino IDE.app/Contents/Resources/app/lib/backend/resources/arduino-cli
```

Typical USB port used:

```text
/dev/cu.usbserial-5A490733351
```

If upload fails because the port disappeared, run:

```bash
'/Applications/Arduino IDE.app/Contents/Resources/app/lib/backend/resources/arduino-cli' board list
```

Then upload again with the detected USB serial port.

## Validation Already Done

The project has repeatedly passed:

- JavaScript syntax parsing via macOS JavaScript engine
- Arduino compile for M5StickCPlus2
- Upload with esptool hash verification

Recent compile size after logo and examples:

```text
Sketch uses about 37% of program storage.
Global variables use about 15% of dynamic memory.
```

## How To Use The Web App

1. Upload the sketch to the M5StickC Plus2.
2. Wait for the M5Stick to reboot.
3. Connect laptop/tablet/phone Wi-Fi to:

```text
PhysicsLab-M5
```

4. Open:

```text
http://192.168.4.1
```

5. If the old page appears, force refresh:

```text
Cmd + Shift + R
```

## Important Design Decisions

- The web app runs directly on the M5Stick. There is no external server.
- No school Wi-Fi credentials are needed.
- The dashboard polls `/data`, but records only new firmware samples using `sampleId`.
- Time values come from the M5Stick (`sampleMs`), not from browser polling time.
- Analysis examples are intentionally short and classroom-oriented.
- Ultrasonic mode shows one primary selected quantity at a time because distance, velocity, and acceleration have different units.

## Next Recommended Work

When hardware testing is available:

1. Test accelerometer zeroing on a stable table.
2. Test gyroscope zeroing while stationary.
3. Test load-cell tare with known masses and adjust calibration factor if needed.
4. Test ultrasonic distance at known distances.
5. Compare 5/10/20 Hz sampling for noise and responsiveness.

Good next software features:

- Demo mode with generated data
- CSV import for offline analysis
- Automatic printable/PDF lab report
- Experiment templates:
  - Hooke's law
  - impulse and collision
  - harmonic oscillation
  - motion with ultrasonic sensor

## Notes

- The chat history itself may not be available in every Codex app/session.
- This file is the permanent project-local history and should be updated after major changes.

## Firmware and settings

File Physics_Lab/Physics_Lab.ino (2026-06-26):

#include <M5StickCPlus2.h>
#include <WiFi.h>
#include <WiFiUdp.h>
#include <WebServer.h>
#include <OneWire.h>
#include <DallasTemperature.h>
#include "HX711.h"
#include "web_dashboard.h"
#include "logo_asset.h"

// Classroom wireless mode: the M5StickC Plus2 creates its own Wi-Fi network.
const char* apSsid = "PhysicsLab-M5";
IPAddress broadcastAddress(192, 168, 4, 255);

// UDP Ports
const int accelPort = 4210;
const int gyroPort  = 4211;
const int forcePort = 4213;
const int ultraPort = 4215;
const int tempPort  = 4216;

WiFiUDP udp;
WebServer server(80);

// Pins
#define TRIG_PIN 26  // G26, DFRobot URM10 TRIG
#define ECHO_PIN 25  // G25, DFRobot URM10 ECHO
#define DT 36        // HX711 DOUT primary candidate
#define DT_ALT 25    // HX711 DOUT alternate candidate for the shared G36/G25 port
#define SCK 26       // HX711 SCK
#define TEMP1_PIN 25 // DS18B20 T1 data
#define TEMP2_PIN 26 // DS18B20 T2 data

HX711 scale;
const float SCALE_FACTOR = 48163.7;
uint8_t activeHx711DtPin = DT;
uint8_t hx711RawZeroCount = 0;
OneWire oneWireTemp1(TEMP1_PIN);
OneWire oneWireTemp2(TEMP2_PIN);
DallasTemperature tempSensor1(&oneWireTemp1);
DallasTemperature tempSensor2(&oneWireTemp2);

int mode = 0;
const int maxMode = 5;
uint16_t sampleRateHz = 10;
unsigned long sampleIntervalMs = 100;
unsigned long lastSampleDue = 0;
unsigned long sampleTimestampMs = 0;
unsigned long sampleSequence = 0;

struct SampleRecord {
  unsigned long id;
  unsigned long timestampMs;
  uint8_t mode;
  float ax, ay, az;
  float gx, gy, gz;
  float force;
  float distance, velocity, acceleration;
  float temp1, temp2, tempDelta;
  float battery;
};

const uint16_t sampleBufferSize = 512;
SampleRecord sampleBuffer[sampleBufferSize];
uint16_t sampleBufferHead = 0;
uint16_t sampleBufferCount = 0;

unsigned long lastBatteryUpdate = 0;
float lastBatteryVoltage = 0;

float prev_distance = -1, prev_velocity = 0;
unsigned long prev_time = 0;
float smoothed_distance = -1;
float distanceOffset = 0;

float latestAx = 0, latestAy = 0, latestAz = 0;
float latestGx = 0, latestGy = 0, latestGz = 0;
float latestForce = 0;
float latestDistance = 0, latestVelocity = 0, latestAcceleration = 0;
float latestTemp1 = 0, latestTemp2 = 0, latestTempDelta = 0;
float rawAx = 0, rawAy = 0, rawAz = 0;
float rawGx = 0, rawGy = 0, rawGz = 0;
float accelOffsetX = 0, accelOffsetY = 0, accelOffsetZ = 0;
float gyroOffsetX = 0, gyroOffsetY = 0, gyroOffsetZ = 0;

void applyCalibration(String target);
void applySampleRate(uint16_t requestedRate);
void applyMode(uint8_t requestedMode);
void beginForceScale(uint8_t dataPin, bool tareScale);
void tryAlternateForceDataPin();

// Display helpers
void drawFooter() {
  M5.Lcd.setTextSize(1);
  M5.Lcd.setTextColor(WHITE, BLACK);
  M5.Lcd.setCursor(0, M5.Lcd.height() - 20);
  M5.Lcd.print("@Sotiris Kaproulias");
}

void drawBattery(float voltage) {
  int width = 30, height = 12;
  int x = M5.Lcd.width() - width - 4, y = 2;
  float percent = constrain((voltage - 3.2) / (4.2 - 3.2), 0.0, 1.0);
  int fill = percent * (width - 4);

  M5.Lcd.fillRect(x - 65, y - 2, 100, height + 4, BLACK);
  M5.Lcd.drawRect(x, y, width, height, WHITE);
  M5.Lcd.fillRect(x + width, y + 3, 2, 6, WHITE);
  M5.Lcd.fillRect(x + 2, y + 2, fill, height - 4, percent < 0.2 ? RED : GREEN);
  M5.Lcd.setTextSize(1.5);
  M5.Lcd.setTextColor(GREEN, BLACK);
  M5.Lcd.setCursor(x - 50, y);
  M5.Lcd.printf("%.2fV", voltage);
}

void beginForceScale(uint8_t dataPin, bool tareScale) {
  activeHx711DtPin = dataPin;
  hx711RawZeroCount = 0;
  scale.begin(activeHx711DtPin, SCK);
  scale.set_scale(SCALE_FACTOR);
  if (tareScale) scale.tare(10);
}

void tryAlternateForceDataPin() {
  beginForceScale(activeHx711DtPin == DT ? DT_ALT : DT, false);
}

void displayMode() {
  const char* modes[] = {"Accel", "Gyro", "Force", "WiFi Info", "Ultrasonic", "Heat"};
  M5.Lcd.setTextSize(2);
  M5.Lcd.setTextColor(CYAN, BLACK);
  M5.Lcd.fillRect(0, 0, 160, 20, BLACK);
  M5.Lcd.setCursor(0, 0);
  M5.Lcd.printf("%s", modes[mode]);
  drawFooter();
}

void showSplashScreen() {
  M5.Lcd.fillScreen(BLACK);
  M5.Lcd.setTextColor(CYAN);
  M5.Lcd.setTextSize(2);
  M5.Lcd.setCursor(20, 30);
  M5.Lcd.println("PALLADIO LAB");
  M5.Lcd.setCursor(20, 60);
  M5.Lcd.setTextColor(YELLOW);
  M5.Lcd.println("Physics Tools");
  drawFooter();
  delay(3000);
}

void startAccessPoint() {
  WiFi.mode(WIFI_AP);
  WiFi.softAP(apSsid);
}

const char* getModeName() {
  const char* modes[] = {"Acceleration", "Gyroscope", "Load Cell", "WiFi Info", "Ultrasonic", "Temperature"};
  return modes[mode];
}

void clearSampleBuffer() {
  sampleBufferHead = 0;
  sampleBufferCount = 0;
}

void resetModeState() {
  prev_distance = -1;
  prev_velocity = 0;
  smoothed_distance = -1;
  prev_time = millis();
  lastSampleDue = 0;
  clearSampleBuffer();
}

void recordSample(uint8_t sampleMode, unsigned long timestampMs, unsigned long id) {
  SampleRecord& record = sampleBuffer[sampleBufferHead];
  record.id = id;
  record.timestampMs = timestampMs;
  record.mode = sampleMode;
  record.ax = latestAx;
  record.ay = latestAy;
  record.az = latestAz;
  record.gx = latestGx;
  record.gy = latestGy;
  record.gz = latestGz;
  record.force = latestForce;
  record.distance = latestDistance;
  record.velocity = latestVelocity;
  record.acceleration = latestAcceleration;
  record.temp1 = latestTemp1;
  record.temp2 = latestTemp2;
  record.tempDelta = latestTempDelta;
  record.battery = lastBatteryVoltage;

  sampleBufferHead = (sampleBufferHead + 1) % sampleBufferSize;
  if (sampleBufferCount < sampleBufferSize) sampleBufferCount++;
}

uint16_t sampleBufferIndex(uint16_t chronologicalIndex) {
  uint16_t start = (sampleBufferHead + sampleBufferSize - sampleBufferCount) % sampleBufferSize;
  return (start + chronologicalIndex) % sampleBufferSize;
}

void sendUdpPacket(const char* payload, int port) {
  udp.beginPacket(broadcastAddress, port);
  udp.write((uint8_t*)payload, strlen(payload));
  udp.endPacket();
}

void addCorsHeaders() {
  server.sendHeader("Access-Control-Allow-Origin", "*");
  server.sendHeader("Access-Control-Allow-Methods", "GET, OPTIONS");
  server.sendHeader("Access-Control-Allow-Headers", "Content-Type");
  server.sendHeader("Access-Control-Allow-Private-Network", "true");
}

void handleOptions() {
  addCorsHeaders();
  server.send(204);
}

void handleRoot() {
  addCorsHeaders();
  server.send_P(200, "text/html", DASHBOARD_HTML);
}

void handleLogo() {
  addCorsHeaders();
  server.send_P(
    200,
    "image/png",
    reinterpret_cast<const char*>(assets_palladio_logo_png),
    assets_palladio_logo_png_len
  );
}

void handleData() {
  addCorsHeaders();
  char json[760];
  snprintf(
    json,
    sizeof(json),
    "{\"mode\":%d,\"modeName\":\"%s\",\"ap\":\"%s\",\"ip\":\"%s\",\"battery\":%.2f,"
    "\"sampleId\":%lu,\"sampleMs\":%lu,\"sampleRate\":%u,"
    "\"ax\":%.3f,\"ay\":%.3f,\"az\":%.3f,"
    "\"gx\":%.3f,\"gy\":%.3f,\"gz\":%.3f,"
    "\"force\":%.3f,\"distance\":%.3f,\"velocity\":%.3f,\"acceleration\":%.3f,"
    "\"temp1\":%.3f,\"temp2\":%.3f,\"tempDelta\":%.3f}",
    mode,
    getModeName(),
    apSsid,
    WiFi.softAPIP().toString().c_str(),
    lastBatteryVoltage,
    sampleSequence,
    sampleTimestampMs,
    sampleRateHz,
    latestAx,
    latestAy,
    latestAz,
    latestGx,
    latestGy,
    latestGz,
    latestForce,
    latestDistance,
    latestVelocity,
    latestAcceleration,
    latestTemp1,
    latestTemp2,
    latestTempDelta
  );
  server.send(200, "application/json", json);
}

void sendSampleJson(const SampleRecord& record, bool comma) {
  char json[520];
  snprintf(
    json,
    sizeof(json),
    "%s{\"mode\":%u,\"sampleId\":%lu,\"sampleMs\":%lu,\"sampleRate\":%u,"
    "\"battery\":%.2f,\"ax\":%.3f,\"ay\":%.3f,\"az\":%.3f,"
    "\"gx\":%.3f,\"gy\":%.3f,\"gz\":%.3f,"
    "\"force\":%.3f,\"distance\":%.3f,\"velocity\":%.3f,\"acceleration\":%.3f,"
    "\"temp1\":%.3f,\"temp2\":%.3f,\"tempDelta\":%.3f}",
    comma ? "," : "",
    record.mode,
    record.id,
    record.timestampMs,
    sampleRateHz,
    record.battery,
    record.ax,
    record.ay,
    record.az,
    record.gx,
    record.gy,
    record.gz,
    record.force,
    record.distance,
    record.velocity,
    record.acceleration,
    record.temp1,
    record.temp2,
    record.tempDelta
  );
  server.sendContent(json);
}

void handleSamples() {
  addCorsHeaders();
  unsigned long since = 0;
  bool includeAll = true;
  if (server.hasArg("since")) {
    String sinceArg = server.arg("since");
    long parsed = sinceArg.toInt();
    if (parsed >= 0) {
      since = (unsigned long)parsed;
      includeAll = false;
    }
  }

  if (!includeAll && sampleSequence <= since) {
    char emptyJson[256];
    snprintf(
      emptyJson,
      sizeof(emptyJson),
      "{\"mode\":%d,\"modeName\":\"%s\",\"ap\":\"%s\",\"ip\":\"%s\",\"battery\":%.2f,"
      "\"sampleRate\":%u,\"latestId\":%lu,\"bufferCount\":%u,\"samples\":[]}",
      mode,
      getModeName(),
      apSsid,
      WiFi.softAPIP().toString().c_str(),
      lastBatteryVoltage,
      sampleRateHz,
      sampleSequence,
      sampleBufferCount
    );
    server.send(200, "application/json", emptyJson);
    return;
  }

  char header[256];
  snprintf(
    header,
    sizeof(header),
    "{\"mode\":%d,\"modeName\":\"%s\",\"ap\":\"%s\",\"ip\":\"%s\",\"battery\":%.2f,"
    "\"sampleRate\":%u,\"latestId\":%lu,\"bufferCount\":%u,\"samples\":[",
    mode,
    getModeName(),
    apSsid,
    WiFi.softAPIP().toString().c_str(),
    lastBatteryVoltage,
    sampleRateHz,
    sampleSequence,
    sampleBufferCount
  );

  server.setContentLength(CONTENT_LENGTH_UNKNOWN);
  server.send(200, "application/json", "");
  server.sendContent(header);

  bool comma = false;
  for (uint16_t i = 0; i < sampleBufferCount; i++) {
    const SampleRecord& record = sampleBuffer[sampleBufferIndex(i)];
    if (!includeAll && record.id <= since) continue;
    sendSampleJson(record, comma);
    comma = true;
  }
  server.sendContent("]}");
  server.sendContent("");
}

void configureModeHardware() {
  if (mode == 2) {
    beginForceScale(activeHx711DtPin, false);
    sampleRateHz = 10;
    sampleIntervalMs = 100;
  } else if (mode == 4) {
    pinMode(TRIG_PIN, OUTPUT);
    digitalWrite(TRIG_PIN, LOW);
    pinMode(ECHO_PIN, INPUT);
  } else if (mode == 5) {
    pinMode(TRIG_PIN, INPUT);
    pinMode(ECHO_PIN, INPUT);
    tempSensor1.begin();
    tempSensor2.begin();
    tempSensor1.setResolution(11);
    tempSensor2.setResolution(11);
  }
}

void handleSetMode() {
  if (server.hasArg("mode")) {
    int requestedMode = server.arg("mode").toInt();
    if (requestedMode >= 0 && requestedMode <= maxMode) applyMode((uint8_t)requestedMode);
  }
  handleData();
}

void handleSettings() {
  if (server.hasArg("rate")) {
    applySampleRate((uint16_t)server.arg("rate").toInt());
  }
  handleData();
}

void handleCalibrate() {
  applyCalibration(server.arg("target"));
  handleData();
}

void applyCalibration(String target) {
  if (target == "accel") {
    accelOffsetX = rawAx;
    accelOffsetY = rawAy;
    accelOffsetZ = rawAz;
    latestAx = latestAy = latestAz = 0;
  } else if (target == "gyro") {
    gyroOffsetX = rawGx;
    gyroOffsetY = rawGy;
    gyroOffsetZ = rawGz;
    latestGx = latestGy = latestGz = 0;
  } else if (target == "force") {
    scale.tare(10);
    latestForce = 0;
    hx711RawZeroCount = 0;
  } else if (target == "distance") {
    distanceOffset += latestDistance;
    latestDistance = 0;
    latestVelocity = 0;
    latestAcceleration = 0;
    prev_distance = -1;
    prev_velocity = 0;
    prev_time = millis();
  }
}

void applySampleRate(uint16_t requestedRate) {
  if (requestedRate == 1 || requestedRate == 2 ||
      requestedRate == 5 || requestedRate == 10 || requestedRate == 20 ||
      requestedRate == 50 || requestedRate == 100) {
    sampleRateHz = requestedRate;
    sampleIntervalMs = 1000UL / sampleRateHz;
    lastSampleDue = 0;
  }
}

void applyMode(uint8_t requestedMode) {
  if (requestedMode > maxMode) return;
  mode = requestedMode;
  configureModeHardware();
  resetModeState();
  M5.Lcd.fillScreen(BLACK);
  displayMode();
}

void startWebServer() {
  server.on("/", HTTP_GET, handleRoot);
  server.on("/", HTTP_OPTIONS, handleOptions);
  server.on("/logo.png", HTTP_GET, handleLogo);
  server.on("/logo.png", HTTP_OPTIONS, handleOptions);
  server.on("/data", HTTP_GET, handleData);
  server.on("/data", HTTP_OPTIONS, handleOptions);
  server.on("/samples", HTTP_GET, handleSamples);
  server.on("/samples", HTTP_OPTIONS, handleOptions);
  server.on("/set-mode", HTTP_GET, handleSetMode);
  server.on("/set-mode", HTTP_OPTIONS, handleOptions);
  server.on("/settings", HTTP_GET, handleSettings);
  server.on("/settings", HTTP_OPTIONS, handleOptions);
  server.on("/calibrate", HTTP_GET, handleCalibrate);
  server.on("/calibrate", HTTP_OPTIONS, handleOptions);
  server.begin();
}

// ULTRASONIC FILTERED READING
float getFilteredDistanceCM() {
  pinMode(TRIG_PIN, OUTPUT);
  pinMode(ECHO_PIN, INPUT);
  digitalWrite(TRIG_PIN, LOW); delayMicroseconds(2);
  digitalWrite(TRIG_PIN, HIGH); delayMicroseconds(10);
  digitalWrite(TRIG_PIN, LOW);

  long duration = pulseIn(ECHO_PIN, HIGH, 30000);
  if (duration == 0) return -1;

  float d = duration * 0.0343 / 2.0;
  if (d < 2 || d > 200) return -1;

  if (smoothed_distance < 0) smoothed_distance = d;
  else smoothed_distance = 0.6 * smoothed_distance + 0.4 * d;

  return smoothed_distance;
}

bool detectTemperatureSensors() {
  pinMode(TRIG_PIN, INPUT);
  pinMode(ECHO_PIN, INPUT);
  tempSensor1.begin();
  tempSensor2.begin();
  delay(30);
  return tempSensor1.getDeviceCount() > 0 && tempSensor2.getDeviceCount() > 0;
}

bool detectHx711OnPin(uint8_t dataPin) {
  HX711 probe;
  probe.begin(dataPin, SCK);
  for (uint8_t attempt = 0; attempt < 6; attempt++) {
    if (probe.is_ready()) return true;
    delay(20);
  }
  return false;
}

bool detectForceSensor() {
  if (detectHx711OnPin(DT)) {
    activeHx711DtPin = DT;
    return true;
  }
  if (detectHx711OnPin(DT_ALT)) {
    activeHx711DtPin = DT_ALT;
    return true;
  }
  return false;
}

bool detectUltrasonicSensor() {
  pinMode(TRIG_PIN, OUTPUT);
  pinMode(ECHO_PIN, INPUT);
  for (uint8_t attempt = 0; attempt < 3; attempt++) {
    digitalWrite(TRIG_PIN, LOW);
    delayMicroseconds(2);
    digitalWrite(TRIG_PIN, HIGH);
    delayMicroseconds(10);
    digitalWrite(TRIG_PIN, LOW);
    long duration = pulseIn(ECHO_PIN, HIGH, 25000);
    float distanceCm = duration * 0.0343 / 2.0;
    if (distanceCm >= 2 && distanceCm <= 250) return true;
    delay(60);
  }
  return false;
}

void autoDetectSensorMode() {
  M5.Lcd.fillScreen(BLACK);
  M5.Lcd.setTextSize(2);
  M5.Lcd.setTextColor(CYAN, BLACK);
  M5.Lcd.setCursor(0, 0);
  M5.Lcd.println("Detecting...");

  bool heatFound = detectTemperatureSensors();
  bool forceFound = false;
  bool ultraFound = false;

  if (!heatFound) {
    ultraFound = detectUltrasonicSensor();
    if (!ultraFound) forceFound = detectForceSensor();
  }

  uint8_t detectedMode = 0;
  uint8_t foundCount = 0;
  if (heatFound) {
    detectedMode = 5;
    foundCount++;
  }
  if (forceFound) {
    detectedMode = 2;
    foundCount++;
  }
  if (ultraFound) {
    detectedMode = 4;
    foundCount++;
  }

  if (foundCount == 1) {
    applyMode(detectedMode);
    M5.Lcd.setCursor(0, 24);
    M5.Lcd.setTextColor(GREEN, BLACK);
    if (detectedMode == 5) M5.Lcd.println("Auto: Heat");
    else if (detectedMode == 2) M5.Lcd.println("Auto: Force");
    else if (detectedMode == 4) M5.Lcd.println("Auto: Sonar");
    delay(900);
    return;
  }

  applyMode(0);
  M5.Lcd.setCursor(0, 24);
  M5.Lcd.setTextColor(YELLOW, BLACK);
  if (foundCount == 0) M5.Lcd.println("Manual mode");
  else M5.Lcd.println("Sensor conflict");
  delay(900);
}

bool sampleCurrentMode(unsigned long now) {
  if (mode == 0) {
    float ax, ay, az;
    M5.Imu.getAccel(&ax, &ay, &az);
    rawAx = ax * 9.81;
    rawAy = ay * 9.81;
    rawAz = az * 9.81;
    latestAx = rawAx - accelOffsetX;
    latestAy = rawAy - accelOffsetY;
    latestAz = rawAz - accelOffsetZ;

    M5.Lcd.setCursor(0, 40);
    M5.Lcd.setTextColor(YELLOW, BLACK);
    M5.Lcd.setTextSize(2);
    M5.Lcd.printf("X: %.2f\nY: %.2f\nZ: %.2f", latestAx, latestAy, latestAz);
    drawFooter();

    char buf[64];
    snprintf(
      buf,
      sizeof(buf),
      "%.2f,%.2f,%.2f,%.2f",
      latestAx,
      latestAy,
      latestAz,
      lastBatteryVoltage
    );
    sendUdpPacket(buf, accelPort);
    return true;
  }

  if (mode == 1) {
    M5.Imu.getGyro(&rawGx, &rawGy, &rawGz);
    latestGx = rawGx - gyroOffsetX;
    latestGy = rawGy - gyroOffsetY;
    latestGz = rawGz - gyroOffsetZ;

    M5.Lcd.setCursor(0, 40);
    M5.Lcd.setTextColor(YELLOW, BLACK);
    M5.Lcd.setTextSize(2);
    M5.Lcd.printf("Gx: %.2f\nGy: %.2f\nGz: %.2f", latestGx, latestGy, latestGz);
    drawFooter();

    char buf[64];
    snprintf(
      buf,
      sizeof(buf),
      "%.2f,%.2f,%.2f,%.2f",
      latestGx,
      latestGy,
      latestGz,
      lastBatteryVoltage
    );
    sendUdpPacket(buf, gyroPort);
    return true;
  }

  if (mode == 2) {
    if (!scale.is_ready()) {
      if (activeHx711DtPin == DT) tryAlternateForceDataPin();
      M5.Lcd.fillRect(0, 20, 160, 100, BLACK);
      M5.Lcd.setCursor(0, 40);
      M5.Lcd.setTextColor(RED, BLACK);
      M5.Lcd.setTextSize(2);
      M5.Lcd.printf("HX711\nnot ready\nD:%u", activeHx711DtPin);
      drawFooter();
      return false;
    }
    long rawForce = scale.read_average(1);
    long forceDelta = rawForce - scale.get_offset();
    latestForce = forceDelta / SCALE_FACTOR;
    if (rawForce == 0) {
      hx711RawZeroCount++;
      if (hx711RawZeroCount > 10) tryAlternateForceDataPin();
    } else {
      hx711RawZeroCount = 0;
    }
    M5.Lcd.fillRect(0, 20, 160, 100, BLACK);
    M5.Lcd.setCursor(0, 40);
    M5.Lcd.setTextColor(YELLOW, BLACK);
    M5.Lcd.setTextSize(1);
    M5.Lcd.printf("F: %.3f N\nraw:%ld\nD:%u d:%ld", latestForce, rawForce, activeHx711DtPin, forceDelta);
    drawFooter();

    char buf[32];
    snprintf(buf, sizeof(buf), "%.3f,%.2f", latestForce, lastBatteryVoltage);
    sendUdpPacket(buf, forcePort);
    return true;
  }

  if (mode == 3) {
    M5.Lcd.setTextSize(2);
    M5.Lcd.setTextColor(YELLOW, BLACK);
    M5.Lcd.setCursor(0, 40);
    M5.Lcd.printf("AP:\n%s\nIP:\n%s", apSsid, WiFi.softAPIP().toString().c_str());
    drawFooter();
    return true;
  }

  if (mode == 4) {
    float d_cm = getFilteredDistanceCM();
    if (d_cm < 0) return false;

    float dt = (now - prev_time) / 1000.0;
    prev_time = now;
    if (dt <= 0) dt = sampleIntervalMs / 1000.0;

    float d_m = d_cm / 100.0 - distanceOffset;
    float v = (prev_distance >= 0) ? (d_m - prev_distance) / dt : 0;
    float a = (prev_distance >= 0) ? (v - prev_velocity) / dt : 0;
    latestDistance = d_m;
    latestVelocity = v;
    latestAcceleration = a;

    prev_velocity = v;
    prev_distance = d_m;

    M5.Lcd.fillRect(0, 20, 160, 100, BLACK);
    M5.Lcd.setTextColor(YELLOW, BLACK);
    M5.Lcd.setTextSize(2);
    M5.Lcd.setCursor(0, 30);
    M5.Lcd.printf("d: %.2fm\nv: %.2fm/s\na: %.2fm/s^2", d_m, v, a);
    drawFooter();

    char buf[64];
    snprintf(buf, sizeof(buf), "%.3f,%.3f,%.3f", d_m, v, a);
    sendUdpPacket(buf, ultraPort);
    return true;
  }

  if (mode == 5) {
    tempSensor1.requestTemperatures();
    tempSensor2.requestTemperatures();
    float t1 = tempSensor1.getTempCByIndex(0);
    float t2 = tempSensor2.getTempCByIndex(0);
    if (t1 == DEVICE_DISCONNECTED_C || t2 == DEVICE_DISCONNECTED_C) return false;

    latestTemp1 = t1;
    latestTemp2 = t2;
    latestTempDelta = t1 - t2;

    M5.Lcd.fillRect(0, 20, 160, 100, BLACK);
    M5.Lcd.setTextColor(YELLOW, BLACK);
    M5.Lcd.setTextSize(2);
    M5.Lcd.setCursor(0, 30);
    M5.Lcd.printf("T1: %.1fC\nT2: %.1fC\ndT: %.1fC", latestTemp1, latestTemp2, latestTempDelta);
    drawFooter();

    char buf[64];
    snprintf(buf, sizeof(buf), "%.2f,%.2f,%.2f,%.2f", latestTemp1, latestTemp2, latestTempDelta, lastBatteryVoltage);
    sendUdpPacket(buf, tempPort);
    return true;
  }

  return false;
}

void setup() {
  Serial.begin(115200);
  M5.begin();
  M5.Imu.begin();
  M5.Power.begin();
  M5.Lcd.setRotation(1);
  showSplashScreen();
  M5.Lcd.fillScreen(BLACK);

  startAccessPoint();
  startWebServer();

  tempSensor1.begin();
  tempSensor2.begin();
  tempSensor1.setResolution(11);
  tempSensor2.setResolution(11);

  udp.begin(accelPort);
  autoDetectSensorMode();
  prev_time = millis();
  lastSampleDue = 0;
}

void loop() {
  M5.update();
  server.handleClient();
  unsigned long now = millis();

  if (now - lastBatteryUpdate >= 1000 || lastBatteryVoltage == 0) {
    lastBatteryVoltage = M5.Power.getBatteryVoltage() / 1000.0;
    drawBattery(lastBatteryVoltage);
    lastBatteryUpdate = now;
  }

  if (M5.BtnA.wasPressed()) {
    applyMode((mode + 1) % (maxMode + 1));
  }

  if (M5.BtnB.wasPressed()) {
    applyMode(mode == 0 ? maxMode : mode - 1);
  }

  if (lastSampleDue == 0 || now - lastSampleDue >= sampleIntervalMs) {
    if (lastSampleDue == 0 || now - lastSampleDue > sampleIntervalMs * 4) {
      lastSampleDue = now;
    } else {
      lastSampleDue += sampleIntervalMs;
    }
    if (sampleCurrentMode(now)) {
      sampleTimestampMs = now;
      sampleSequence++;
      recordSample(mode, sampleTimestampMs, sampleSequence);
    }
  }

  delay(1);
}

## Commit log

2026-06-15 Use M5 access point for wireless classroom mode
2026-06-15 Move Arduino sketch into sketch folder
2026-06-25 Document student and teacher UI flow
2026-06-25 Add URM10 wiring and sensor auto-detect
    Configure DFRobot URM10 on TRIG G26 / ECHO G25.
    Add startup sensor auto-detection for DS18B20, HX711, and URM10.
    Update dashboard text and hardware documentation.
2026-06-25 Prioritize URM10 during sensor auto-detect
2026-06-26 Extract device client
2026-06-29 Redesign heat and pendulum experiment workflows
2026-06-29 Add velocity time area analysis
2026-07-01 Extract sonar numeric helpers
